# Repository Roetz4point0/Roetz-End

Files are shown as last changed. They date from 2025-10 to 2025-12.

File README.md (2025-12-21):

# 🔥 Roetz-End – Co-Extrusion Hotend (Open Beta)
**by Jan Roetz / Roetz4.0**

---

## 🧠 Overview
The **Roetz-End** is an open-source, high-performance Co-Extrusion Hotend designed for  
**Directional Material Deposition (DMD)** — a process where each filament’s deposition  
is *actively controlled based on the print head’s movement direction.*

Hotend

This marks the first public release of the Roetz-End concept —  
a platform for multi-material co-extrusion without mixing, purging, or waste.  

 Cube_Small

🎥 Full context, demonstration and build information:  
👉 [YouTube Release Video](https://youtu.be/6pM_ltAM7_s)

---

## ⚙️ Technical Notes
- Four independent melt channels allow **directional placement** of materials or colors.  
- No purge blocks, no priming towers, no poop.  
- Flow rates up to **200 mm³/s** possible (depending on filament).

---

## 🛠️ Build Guide (Quick Start)

### Required Parts
| Component | Description | Source |
|---|---|---|
| 1x **Hotend** | SLM printed aluminum | Online SLM manufacturer, read the buildguide|
| 1x **Coldend** | SLM printed aluminum | Online SLM manufacturer, read the buildguide |
| 1x **Back Bracing** | (optional) stainless steel sheet metal | Online sheet metal manufacturer, read the buildguide|
| 4x **Heatbreak** V0.9 | M6 (bottom) and Ø6mm cylindrical (top), Go-To: Creality Ender 3 S1 Heatbreak | Local supplier or: https://tinyurl.com/mtvx7jhu "Bimetal Throat" |
| 2x **Heatbreak** V0.91 | 2	Bimetal	M6 thread bottom with 5mm key / copper top | Local supplier or:https://tinyurl.com/4pekduk4 "Chimera Heatbreak" |
| 4x **Heater** | Ø6mm x 20mm lenght, preferably. 24V 50W | Local supplier or: https://tinyurl.com/3yftytx4 "50W 24V" |
| 1x **FAN** | 30x30x10mm Fan, preferably ball bearing and 24V | Local supplier or: https://tinyurl.com/23sj9bh6 "3010 24V" |
| 1x **Nozzle** | Standard RepRap M6 | Local supplier |
| **Screws** | M3-hex in 6-20mm lenght | Standard DIN / ISO |
| **pneumatic couplers** | For Bowden Setup only. MINI-IQS Ø4mm/M6 or POC4/M6 | Local or: https://tinyurl.com/53jsmu88 "POC 4-M6"|
---

### Assembly Overview
1. Check all threads if they are deep enough and run freely.  
2. Check hole sizes if heatbreaks and heater cartridges do fit.
3. Wire heater and thermistor into your printers mainboard
4. Screw heatbreaks and nozzle into the hotend (consider using some teflon tape)
5. Heat up Hotend to 250°C, use soft pliers to thread heatbreaks and nozzle in all the way. (Let it cool down afterwards)
6. Marry Hot- and Coldend. Make sure it seats properly and torque down the 3 screws to close the flexure.

📘 Detailed assembly PDF: [BuildGuide/BuildManual_v0.9-Beta.pdf](./BuildGuide/BuildManual_v0.9-BETA.pdf)

---

## 📜 License
© 2025 Jan Roetz / Roetz4.0  
Licensed under [CC BY-NC-SA 4.0](https://creativecommons.org/licenses/by-nc-sa/4.0/)

You are free to share and adapt this work for **non-commercial** purposes,  
as long as attribution is given and derivative works use the same license.

---

## 💬 Community & Collaboration
This project is open for research and exploration.  
If you modify, build, or test the Roetz-End — share it!  
Post with `#RoetzEnd` or open a discussion under the [Issues tab](../../issues).

---

## 🧾 Files
- [STL Models](./Files)
- [BOM (Bill of Materials)](./BuildGuide/BOM.csv)
- [Build Guide PDF](./BuildGuide/BuildManual_v0.9-BETA.pdf)

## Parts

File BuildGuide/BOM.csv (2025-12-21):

Position | Component | Quantity | Material | Specification | Source
1 | Hotend Body | 1 | Aluminum (SLM printed) | R4 - PIE | Online SLM manufacturer, read the buildGuide
2 | Coldend Body | 1 | Aluminum (SLM printed) | R4 Coldend | Online SLM manufacturer, read the buildGuide
3 | Back Bracing **(optional)** | 1 | Stainless Steel | Sheet metal 1mm, for rigidity | Online sheet metal manufacturer, read the buildGuide
4.1 | Heatbreak for V0.9 Hotend (4x) | 4 | Bimetal | M6 thread bottom / Ø6mm top | https://tinyurl.com/mtvx7jhu
4.2 | Heatbreak for V0.91 Hotend (2x) | 2 | Bimetal | "M6 thread bottom with 5mm key / copper top" | "https://tinyurl.com/4pekduk4"
5 | Heater Cartridge | 4 | – | Ø6x20mm, 24V 50W | https://tinyurl.com/3yftytx4
6 | Thermistor | 1 | – | NTC 100K (B3950) | Local supplier
7 | Fan | 1 | – | 30x30x10mm, 24V Ball Bearing | https://tinyurl.com/23sj9bh6
8 | Nozzle | 1 | Brass / Hardened Steel | Standard RepRap M6 | Local supplier
9 | Screws | – | Steel | M3 hex, 6–20mm | DIN / ISO
10 | Pneumatic Couplers | 4 | Brass / Plastic | MINI-IQS Ø4mm/M6 or POC4/M6 | https://tinyurl.com/53jsmu88
11 | PTFE Tube | 4 | PTFE | Ø2mm ID / Ø4mm OD | Amazon / AliExpress

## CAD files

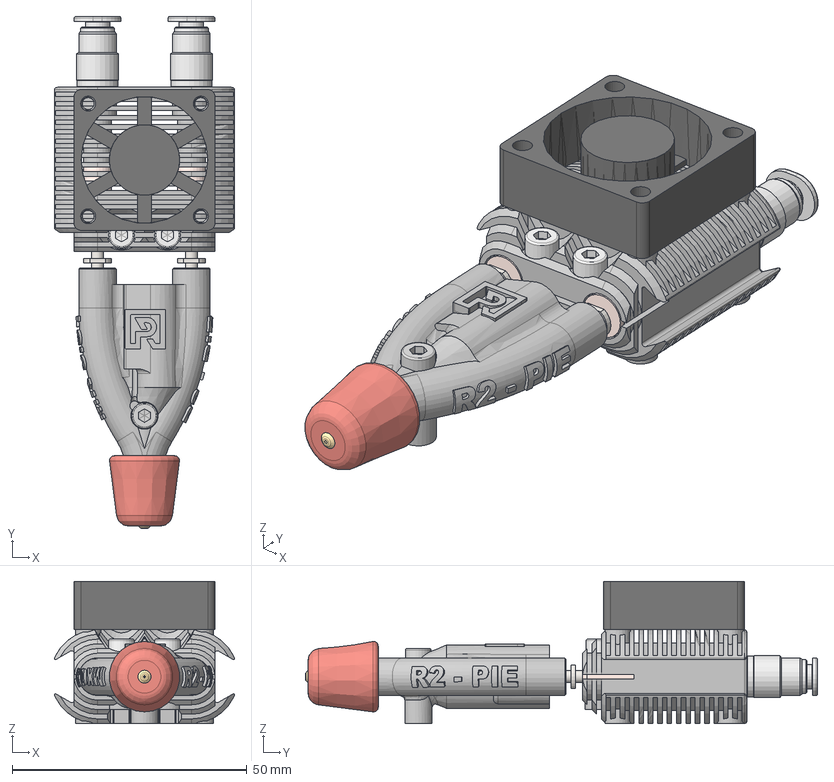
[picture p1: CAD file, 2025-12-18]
Files/Hotends/R2/R2-FULL Mk 0.91.step
38.4 x 109.1 x 30.3 mm
Nozzle_M6_0,5mm
HE_ColdendFan_30x30
HE_ColdendFan_30x30_1
POC04M6C-mdt x 2
Chimera Heatbreak x 2
PTFE Tubing
Heatsock
DIN 912 - M3 x 0.5 x 12 Edelstahl A4-80 Einfach x 2
DIN 912 - M3 x 0.5 x 5 Stahl 4.6 Einfach

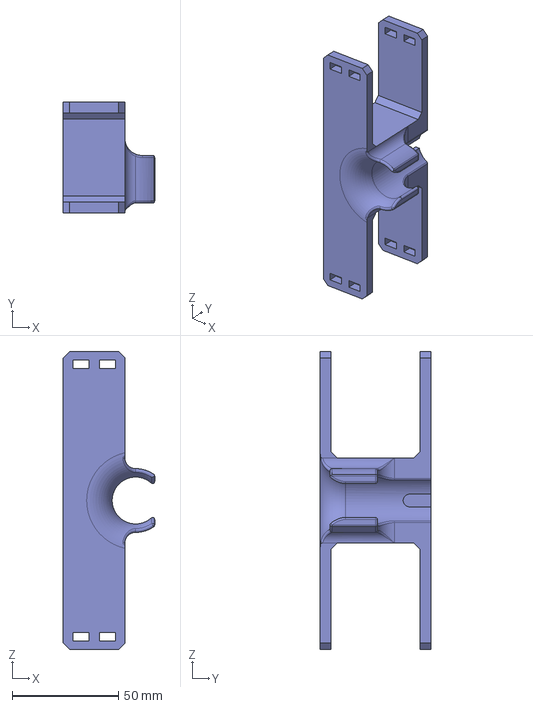
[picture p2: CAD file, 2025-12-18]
Files/Hotends/2x Extruder mount.step
43.0 x 52.0 x 140.0 mm

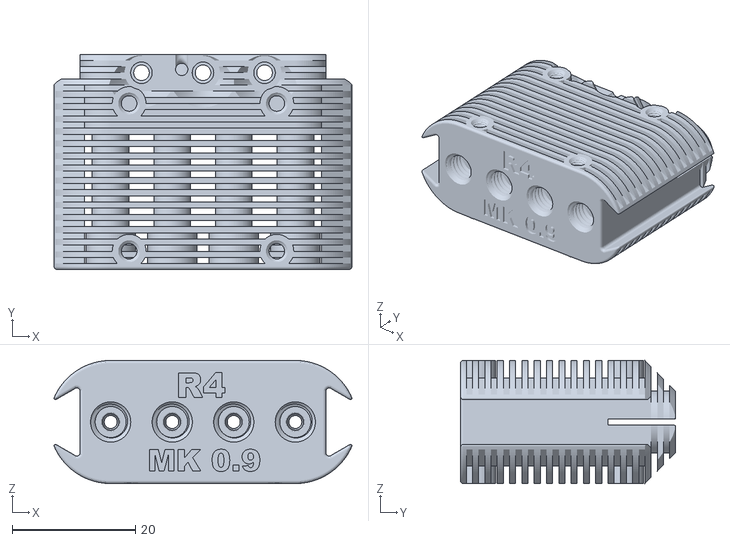
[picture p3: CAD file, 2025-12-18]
Files/Hotends/R4/R4_Coldend_Mk0.9.stl
48.4 x 35.0 x 20.0

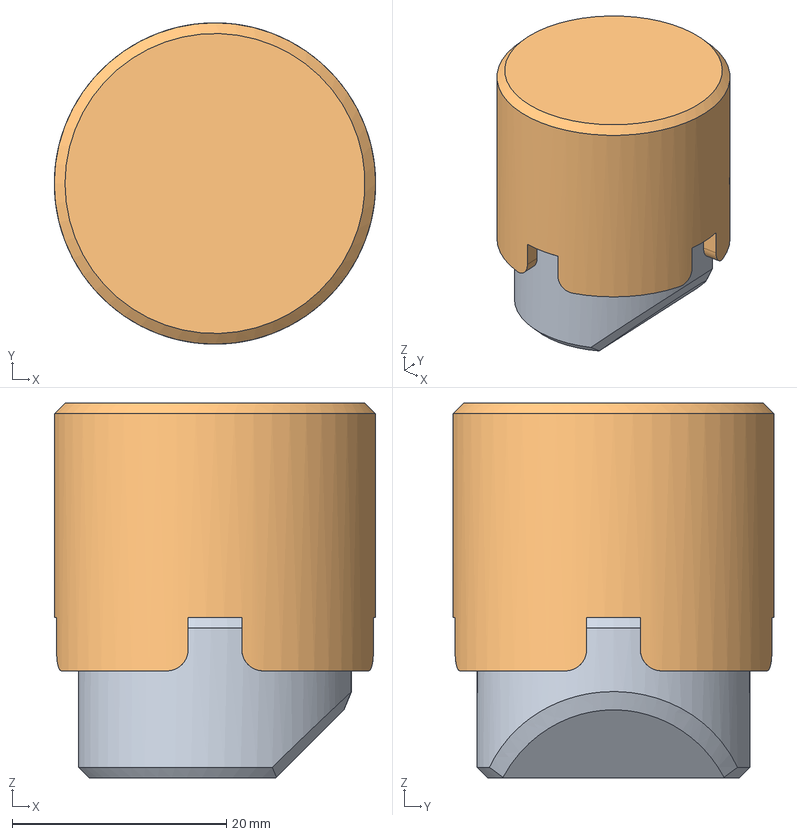
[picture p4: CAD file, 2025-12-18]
Files/Hotends/Heatsock Mold.step
30.0 x 30.0 x 35.0 mm
Komponente7
Komponente8

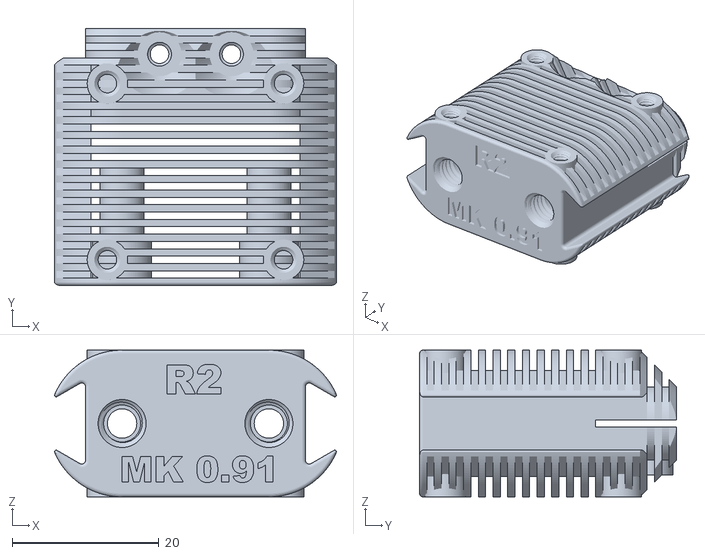
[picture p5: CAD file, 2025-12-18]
Files/Hotends/R2/R2-Coldend Mk 0.91.stl
38.4 x 35.0 x 20.0

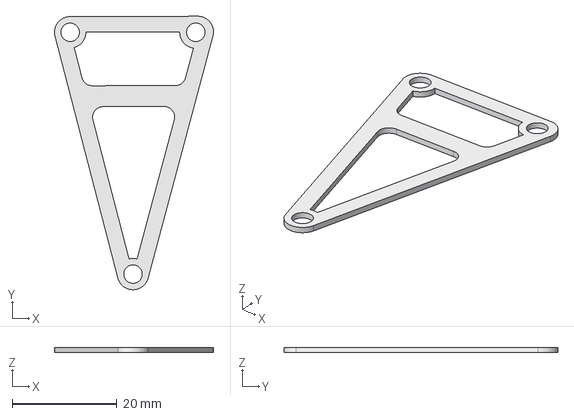
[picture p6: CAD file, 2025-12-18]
Files/Hotends/R4/R4_backbrace.step
30.4 x 52.3 x 1.00 mm

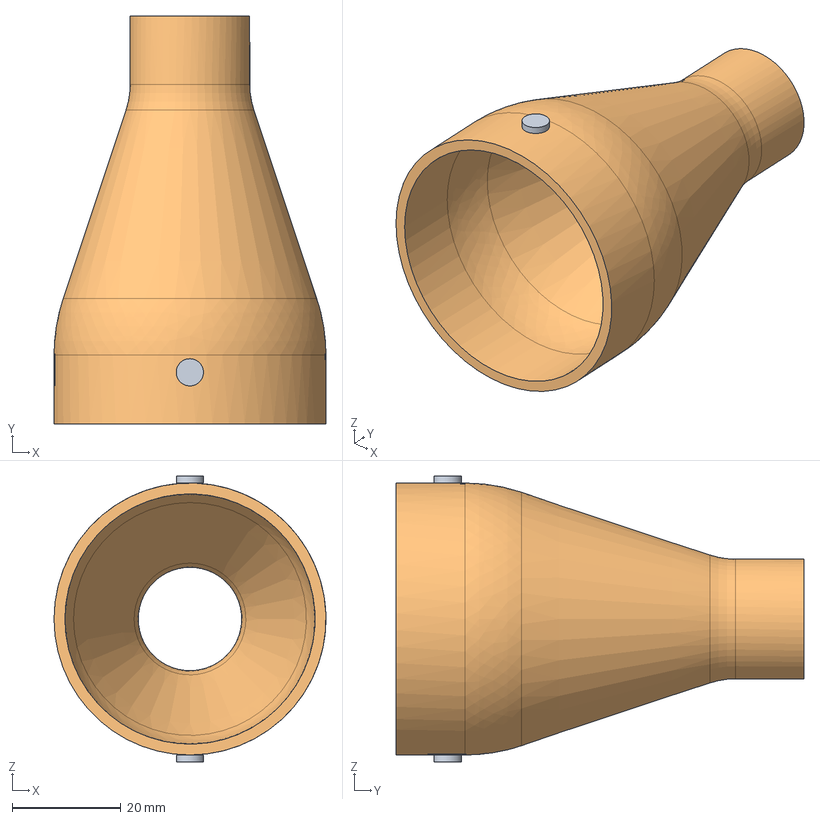
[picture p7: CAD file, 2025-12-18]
Files/Hotends/Makita to CPAP Adapter.step
50.0 x 75.0 x 52.5 mm

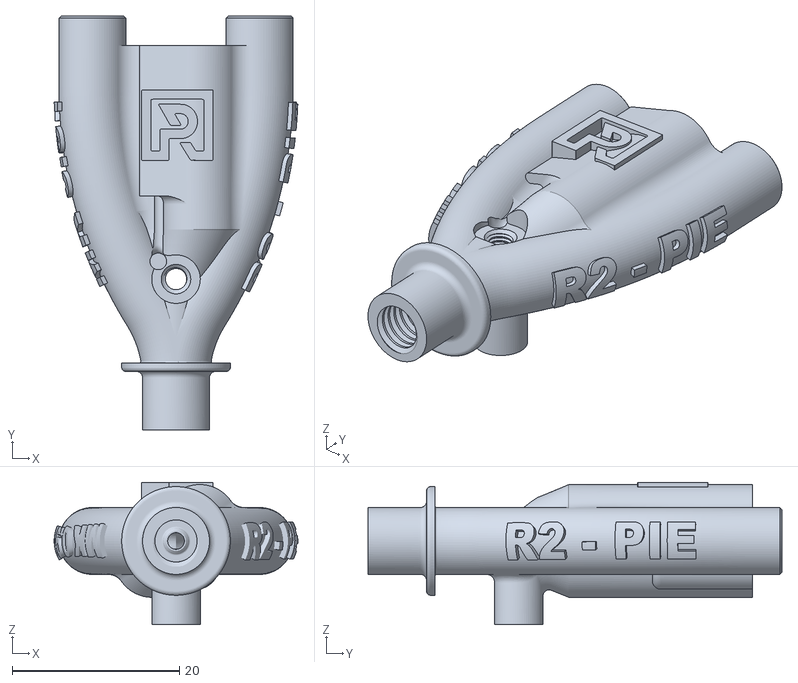
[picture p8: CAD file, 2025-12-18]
Files/Hotends/R2/R2-PIE Mk 0.91.stl
29.1 x 49.5 x 17.0

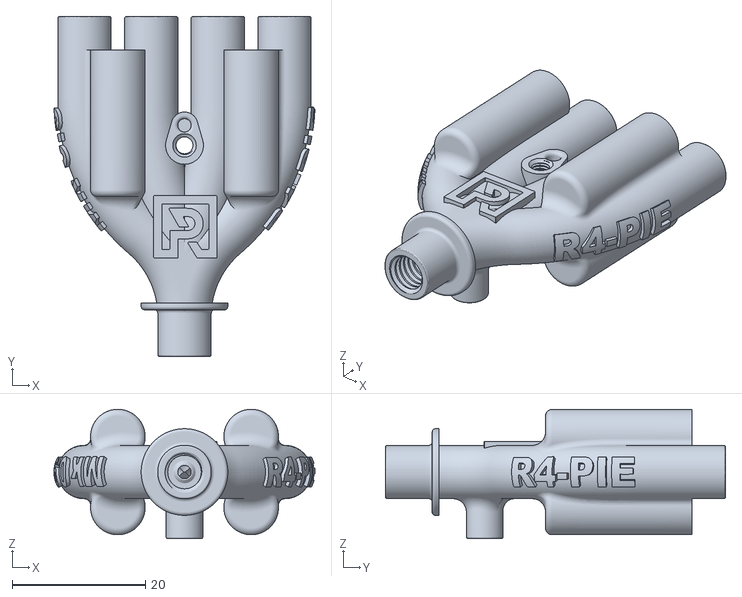
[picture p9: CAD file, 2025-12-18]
Files/Hotends/R4/R4-PIE_Mk0.9.stl
39.1 x 51.0 x 19.4

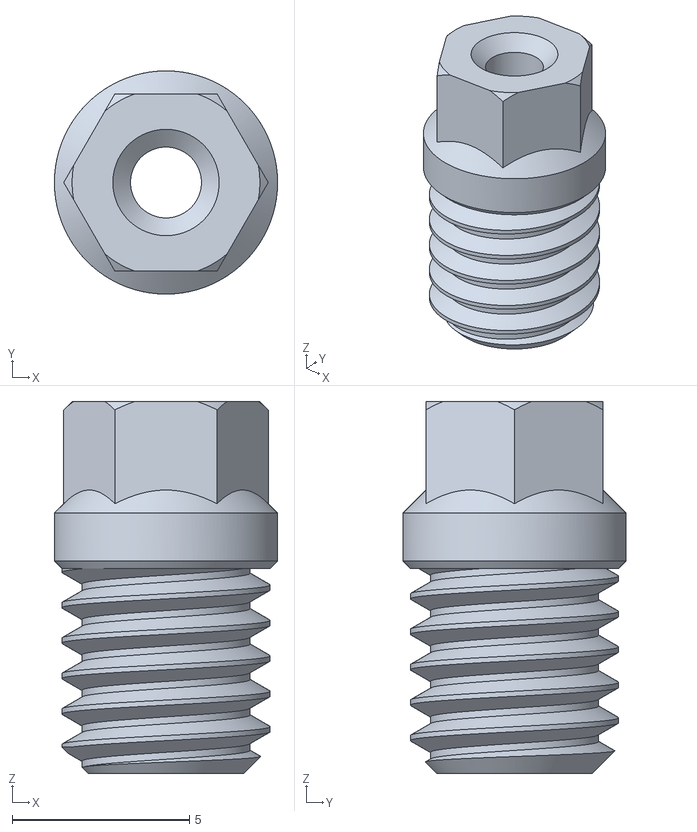
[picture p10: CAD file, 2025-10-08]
Files/Hotends/DirectDrive_Liner.stl
6.30 x 6.30 x 10.5

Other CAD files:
Files/Hotends/R4/R4_Backbrace.stl

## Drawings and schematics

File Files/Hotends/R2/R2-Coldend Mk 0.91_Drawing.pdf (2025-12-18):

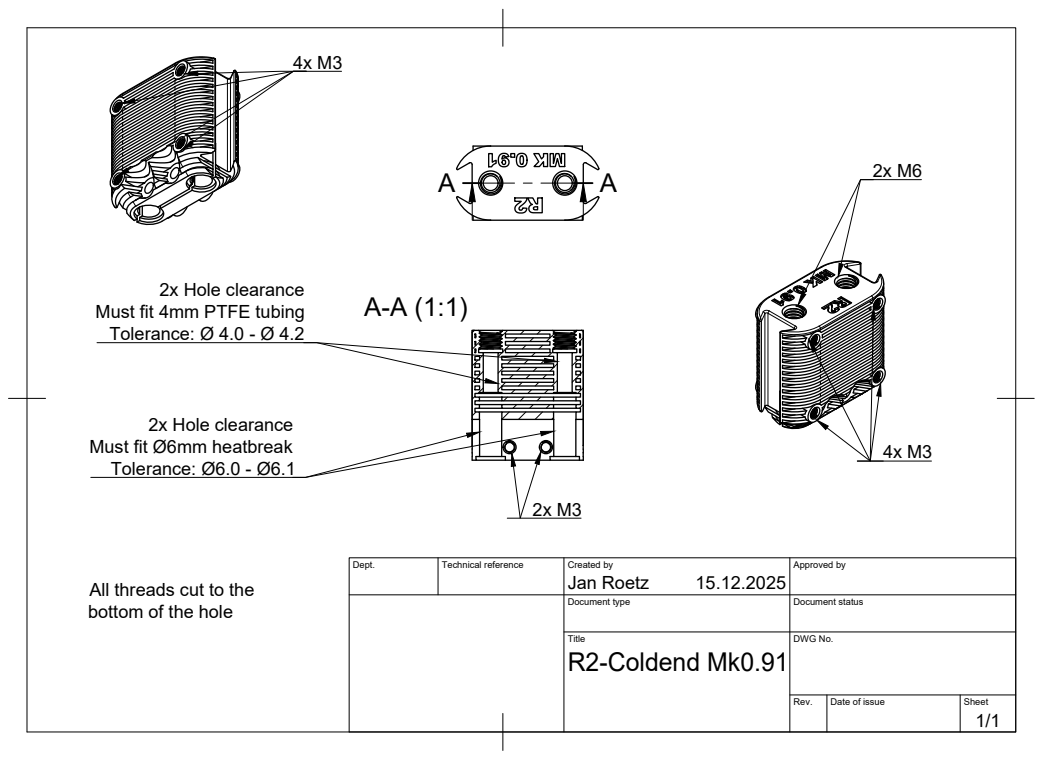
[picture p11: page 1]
2x Hole clearance

Must fit 4mm PTFE tubing
Tolerance: Ø 4.0 - Ø 4.2

Must fit Ø6mm heatbreak
Tolerance: Ø6.0 - Ø6.1

Dept. | Technical reference | Created by Jan Roetz 15.12.2025 | Approved by

All threads cut to the
bottom of the hole

Document type | Document status

Title R2-Coldend Mk0.91 | DWG No.

Rev. | Date of issue | Sheet 1/1

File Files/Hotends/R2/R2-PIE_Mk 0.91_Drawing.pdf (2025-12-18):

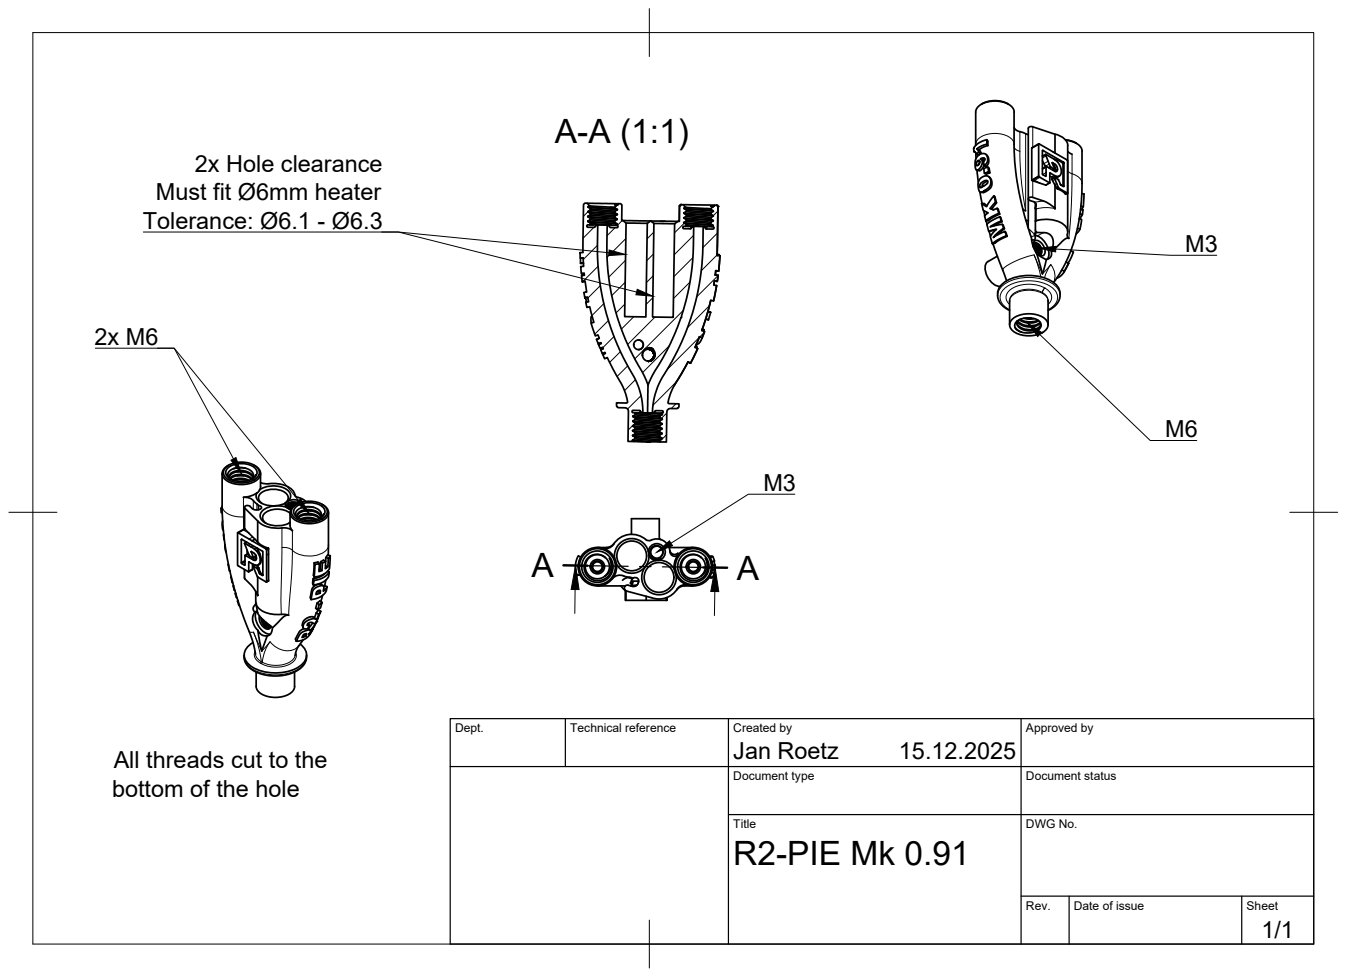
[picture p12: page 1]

2x Hole clearance
Must fit Ø6mm heater
Tolerance: Ø6.1 - Ø6.3

Dept. | Technical reference | Created by Jan Roetz 15.12.2025 | Approved by

All threads cut to the
bottom of the hole

Document type | Document status

Title R2-PIE Mk 0.91 | DWG No.

Rev. | Date of issue | Sheet 1/1

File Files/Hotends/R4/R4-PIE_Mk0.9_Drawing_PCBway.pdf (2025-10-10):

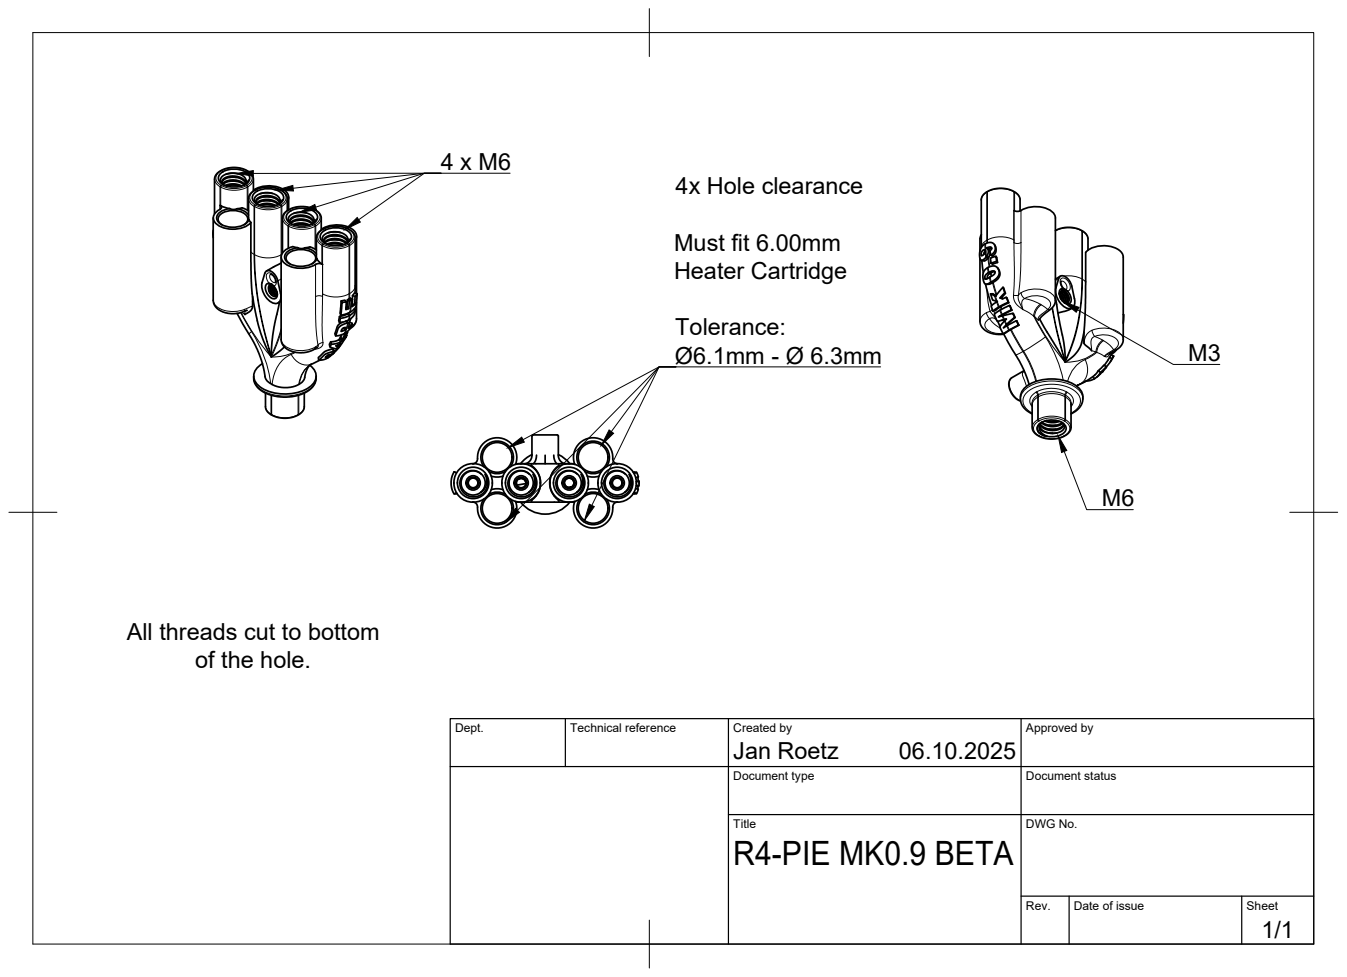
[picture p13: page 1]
4x Hole clearance; Must fit 6.00mm Heater Cartridge

All threads cut to bottom

of the hole.

Dept. | Technical reference | Created by Jan Roetz 06.10.2025 | Approved by

Document type | Document status

Title R4-PIE MK0.9 BETA | DWG No.

Rev. | Date of issue | Sheet 1/1

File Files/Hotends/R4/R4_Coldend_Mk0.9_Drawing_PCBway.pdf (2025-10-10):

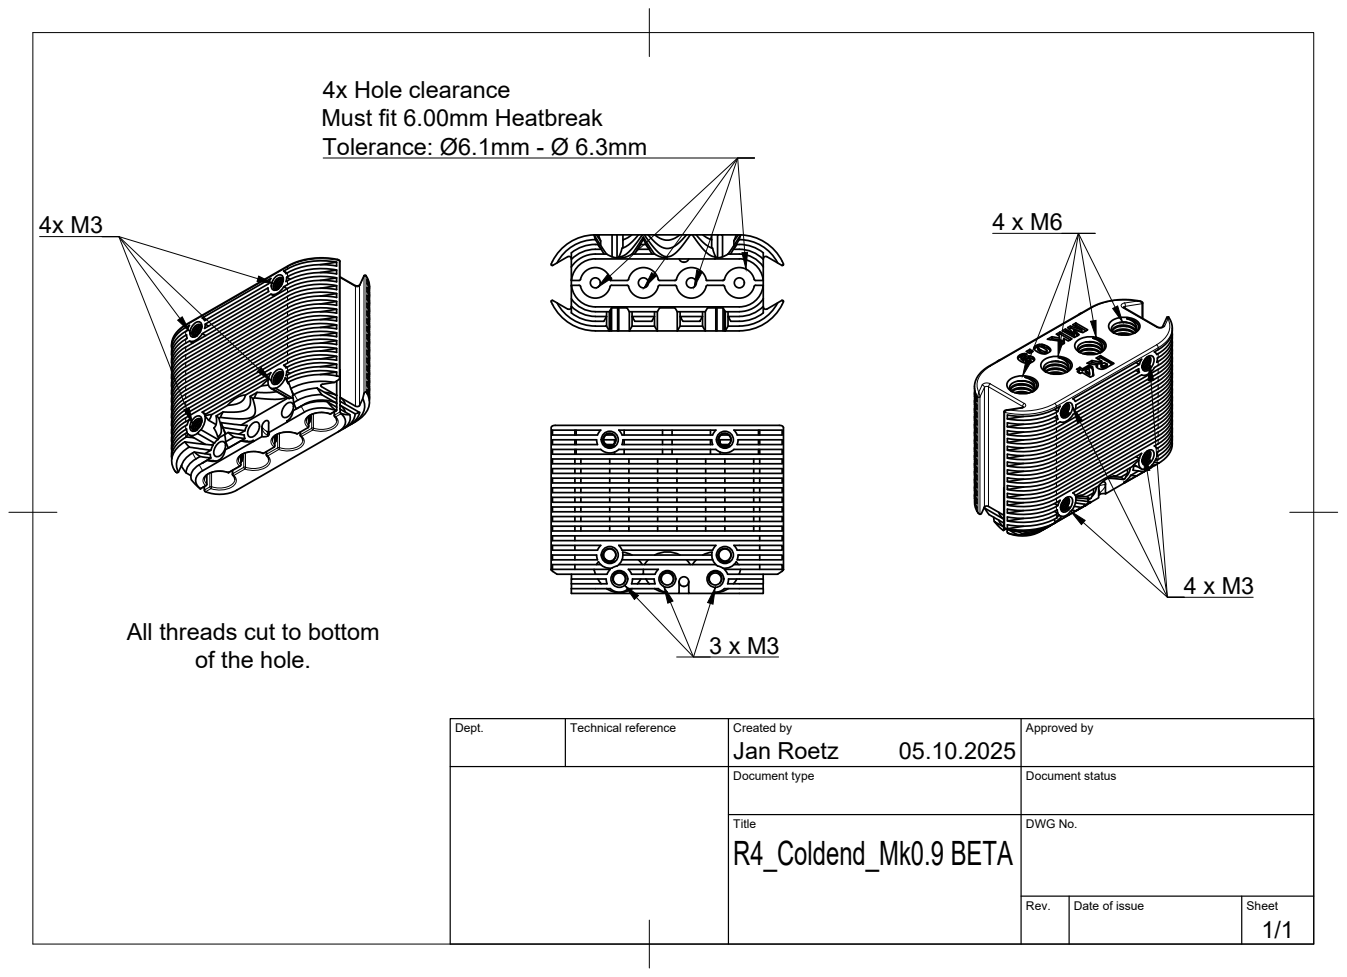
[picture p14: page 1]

4x Hole clearance
Must fit 6.00mm Heatbreak
Tolerance: Ø6.1mm - Ø 6.3mm

All threads cut to bottom

of the hole.

Dept. | Technical reference | Created by Jan Roetz 05.10.2025 | Approved by

Document type | Document status

Title R4_Coldend_Mk0.9 BETA | DWG No.

Rev. | Date of issue | Sheet 1/1

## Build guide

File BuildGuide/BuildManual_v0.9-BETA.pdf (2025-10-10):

## Roetz-End Build Manual v0.9 – BETA

Author: Jan Roetz / Roetz 4.0
License: CC BY-NC-SA 4.0
Repository: https://github.com/Roetz4point0/Roetz-End
Date: October 2025

### 1. Introduction

The parts for the Roetz-end assembly can be aquired through different services. Fans, heatbreaks, heater, etc. are all standard parts and can be bought through provided link off of aliexpress or at your local 3d printer shop. The hotend and coldend can be 3d printed in the slm process – there are plenty of manufacturers to choose from. I’ll be showing a how to configure the parts on the PCBway website.

1.1 Download R4-PIE_Mk0.9.stl (https://github.com/Roetz4point0/Roetz-End/blob/main/Files/R4-PIE_Mk0.9.stl) and R4_Coldend_Mk0.9.stl (https://github.com/Roetz4point0/Roetz-End/blob/main/Files/R4_Coldend_Mk0.9.stl) from the Files directory of the github.
1.2 Upload them to www.pcbway.com
1.3 If you want to cut threads/ check tolerances by yourself, choose the desired quantity and use the following material parameters: The price for both items should be around 70 USD.

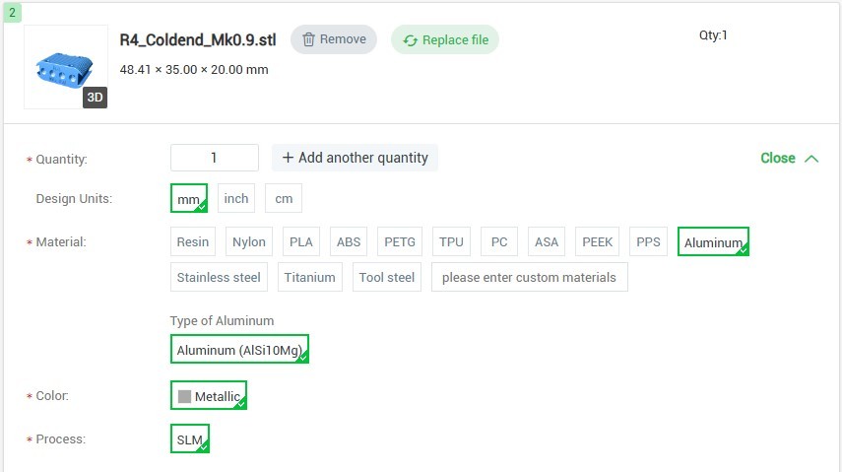
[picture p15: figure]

1.4 If you want to have the fully threaded version, select the same material/quantity as in 1.3. On top, check „yes“ for threads and upload the corresponding technical drawing (R4-PIE_Mk0.9_Drawing_PCBway.pdf, (https://github.com/Roetz4point0/Roetz-End/blob/main/Files/R4-PIE_Mk0.9_Drawing_PCBway.pdf) Coldend_Mk0.9_Drawing_PCBway.pdf (https://github.com/Roetz4point0/Roetz-End/blob/main/Files/R4_Coldend_Mk0.9_Drawing_PCBway.pdf) )which contains all neccessary information.
The price for both items should be around 150 USD.

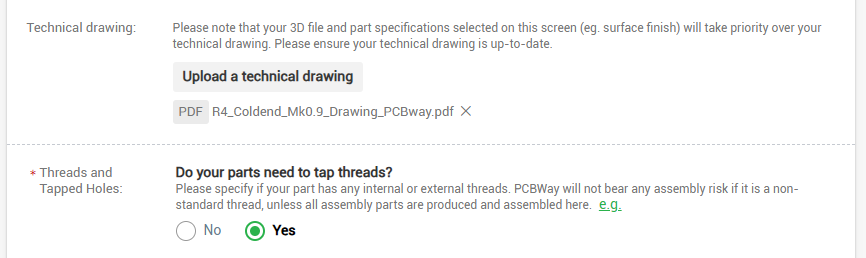
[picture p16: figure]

### 2. Suggested Tools

- M3 / M6 taps and tap wrench
- Ø 6 mm / Ø 2 mm reamers or drills
- Calipers
- Allen key set
- Pliers set
- Thread seal tape (PTFE)

### 3. Assembly Steps

🟨 Raw Version Preparation

Both SLM-printed parts are shipped straight from the machine.
Before assembly, you’ll need to cut all threads and ensure that every accessory fits correctly.
The threads are already modeled into the Hotend and Coldend, so your tap will usually follow them naturally, but it is crucial that the heatbreaks M6 threads are in line with the melt channel bore.

Use cutting oil when tapping, but make sure to remove all residue before final
heating or assembly.

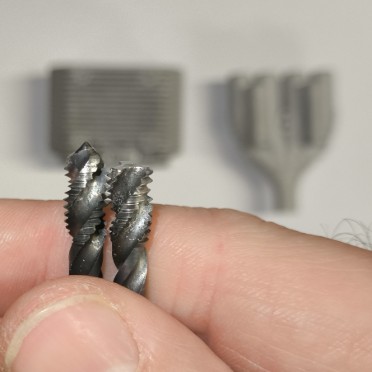
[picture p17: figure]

If the heatbreaks do not seat fully, use a bottoming (ground-off) M6 tap to reach the
very bottom of the threads.

All Ø6 mm holes must be large enough to accept both heatbreaks and heater cartridges.
If the fit is too tight from the machine, lightly run a flat-ground 6 mm drill or endmill through the bores until the components slide in smoothly.

🟧 Pre-Machined Version Preparation

Both the Hotend and Coldend have been finished to final tolerance.
All critical holes and threads are ready for immediate assembly — you do not need to re-tap or re-drill anything.

Before starting, visually inspect all threads and ensure they run freely.
If any chips or powder remain from post-processing, clean the parts with compressed air or a soft brush.

Check that your heatbreaks and heater cartridges slide in without resistance. Once verified, you can proceed directly with the main assembly steps.

Step 2 – Install Heatbreaks
1. Clean the hotend and channels with shop air or a strong vacuum.
2. Apply PTFE tape or high-temperature thread sealant to the M6 threads.
3. Thread in all four heatbreaks by hand until seated.

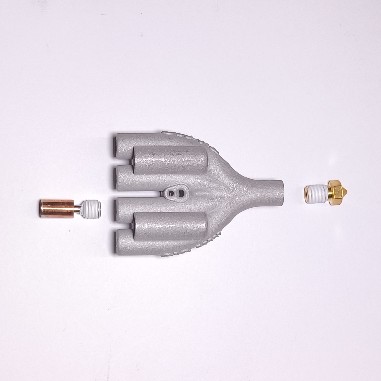
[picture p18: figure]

4. Heat the hotend to ≈ 250 °C and retighten using soft pliers (you can use insulation tape around the jaws of the pliers)
5. Let the assembly cool to room temperature before continuing.
6. Dont screw in the nozzle – this will be the last step.
Step 3 – Install Heaters and Thermistor

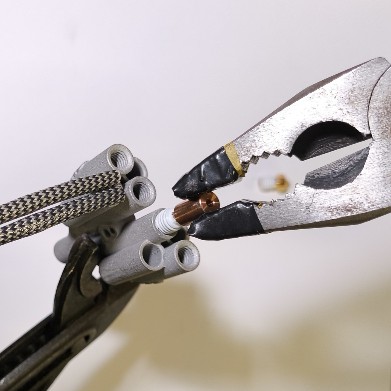
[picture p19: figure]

1. Insert the Ø6 mm × 20 mm heater cartridges into their respective bores. You can use thermal paste for maximum performance but it is not neccessary.
2. Mount the thermistor in the central bore and secure it with an M3 screw.
Step 4 – Join Hotend and Coldend
1. Align the Coldend and Hotend so the heatbreaks seat perfectly into their channels.
2. Insert the three M3 clamping screws and tighten them gradually in a cross pattern.

💡 Tip: A gentle amount of torque is enough to hold the hotend in place. If you overtighten and strip the threads you can use an M3 nut as a thread replacement.

Step 5 – Install Fan and Accessories
1. Mount the 30 × 30 mm cooling fan to the front of the Coldend using M3 screws.
2. Attach sensors or ducts via the side dovetail mounts for height
probes or additional cooling.

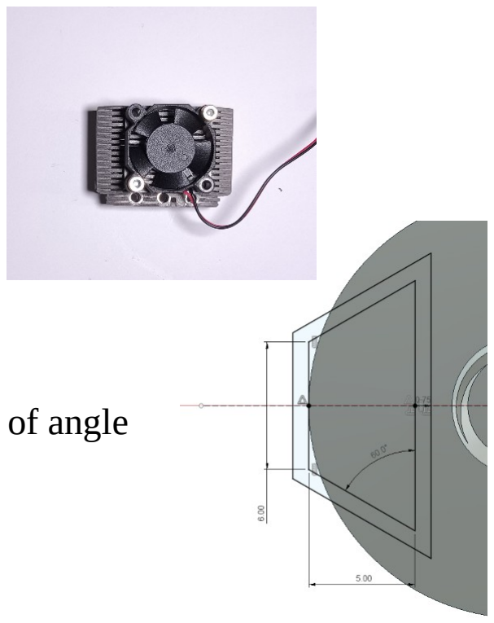
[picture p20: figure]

3. Design your dovetail counterparts with 6mm of throat opening, 60° of angle and 5mm depth or refer to: DIN 654 – D6

Step 6 – Electrical Connections
1. Connect all heater leads and the thermistor to your mainboard or a suitable external relay.
2. Double-check the voltage rating (24 V) and total power draw (≈ 200 W).
3. Verify strain relief and cable routing before the first heat-up.
4. Check that the fan starts automatically when heating begins.

⚠️Warning: Always run initial tests under supervision — high-power heating elements can overrun quickly if the thermistor connection fails.

Step 7 – Calibration & Test Print
1. Heat the assembly slowly. The first heat will eventually burn off any oil left from thread cutting.
2. Load filament into all lanes. If run with empty lanes, molten material might push up other channels and clog the system.
3. Extrude some material and flush the system of last bits of powder from manufacturing.
4. Screw the nozzle in and torque it down while heated up.
5. Observe the melt flow and watch for leaks or uneven extrusion.
6. Run a PID tune at ~230 °C to stabilize temperature control.

### 4. Technical Notes

- The Roetz-End operates as a high-flow multi-filament hotend capable of up to 200 mm³/s material throughput. The stated flow rate is achieved with Fiberlogy HS Pla @ 250°C @ 1mm nozzle. Results may vary, there is only very limited data points availiable until now.
- Recommended heater configuration: 4 × 24 V / 50 W cartridges, controlled parallel via solid-state relay.
- Thermistor type: NTC 100 K (B3950) or equivalent.
- All melt channels are independent and feature direct filament paths for clean material separation.
- Standard nozzle interface: M6 × 1 mm, compatible with all common RepRap-style nozzles.
- Dovetail accessory mounts follow DIN 654 – D6 (60°) geometry, 6 mm throat, 5 mm depth.
- Recommended material for SLM parts: AlSi10Mg or similar heat-conductive aluminum alloy.
- For best results, use Klipper or recent Marlin firmware with pressure advance or linear advance enabled.
- Avoid overtightening M3 screws in aluminum — torque ≈ 1 Nm maximum.

### 5. Maintenance

- Inspection: Check all mechanical fasteners, wiring and connectors after the first hour of operation and then periodically every 50 hours.
- Cleaning: Keep the nozzle and the cooling fins free of plastic residue and dust. Use brass brushes or non-abrasive cloth only.
- Fan service: Ensure the 30 mm fan spins freely; replace if bearing noise increases.
- Heater replacement: Always disconnect power before removing heater cartridges. Reapply thermal compound if reused.
- Re-sealing: When disassembling, replace PTFE tape or thread sealant on heatbreaks to maintain tight sealing.
- Calibration: Re-run PID tuning and flow tests after every major rebuild or part replacement.

### 6. License & Credits

🧾 License & Credits

Project: Roetz-End – Directional Material Deposition (Beta) Author: Jan Roetz / Roetz 4.0
Year: 2025
Repository: github.com/Roetz4point0/Roetz-End
License: Creative Commons BY-NC-SA 4.0

You are free to share and adapt this work for non-commercial purposes, provided that proper attribution is given and derivative works are shared under the same license.

All trademarks and product names mentioned (Creality, Bondtech, Prusa, PCBWay, etc.) are the property of their respective owners and are used here for descriptive purposes only.
This documentation is not affiliated with or endorsed by those companies.

## Disclaimer

⚠️

### The Roetz-End is an experimental open-source hardware project provided as-is

without warranty of any kind.

Building, modifying or operating it is done at your own risk.

### Ensure compliance with electrical, mechanical, and thermal safety standards

applicable in your region.

### The author assumes no responsibility for injury, property damage, or loss

resulting from the use or misuse of this design.

By using the provided files or following this manual, you agree to these terms.

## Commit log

2025-12-18 Rename Files/R4-PIE_Mk0.9.stl to Files/Hotends /R4/R4-PIE_Mk0.9.stl
    [R4-PIE_Mk0.9.stl]
2025-12-20 Update BOM with new heatbreak specifications
    Added new heatbreak options for V0.9 and V0.91 hotends.
    [BOM.csv]
2025-12-20 Update Heatbreak specifications in README
2025-12-21 Update BOM.csv with heatbreak link for V0.91
    Added missing heatbreak link for V0.91 Hotend.
    [BOM.csv]
